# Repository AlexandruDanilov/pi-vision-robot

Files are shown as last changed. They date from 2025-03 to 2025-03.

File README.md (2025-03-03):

# Pi Vision Project Documentation

## Chapter I. Practical Utility

Pi Vision is a modular, smart webcam platform designed to keep the subject perfectly centered without reducing image quality. It processes images locally, so it does not affect your computer’s performance. This makes it ideal for streaming and videoconferencing.

The webcam works autonomously in any environment—as long as there is a subject to follow. It’s suitable for any workspace requiring a video connection and can be used for:

- **Videoconferences:** Keeps you centered without manual adjustments for a smooth, professional meeting.
- **Streaming:** Perfect for live streaming (games, events, etc.) by automatically focusing on the subject.
- **Video Recording:** Records high-quality videos like vlogs or tutorials, always keeping the subject in frame.
- **Mobile Robotics:** Can be integrated into mobile robots for autonomous navigation and enhanced interaction.

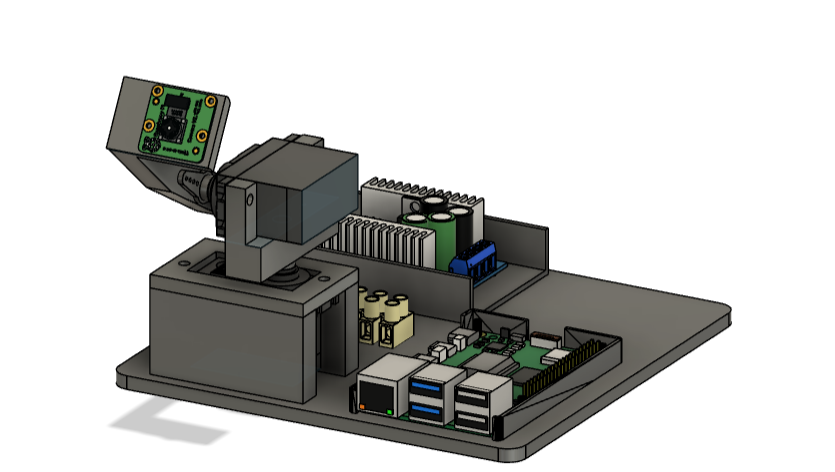
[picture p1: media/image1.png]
Prototype image 1


---

## Chapter II. Mechanics

### 1. Mechanical Design

- **Degrees of Freedom:**  
  The device uses two servo motors to allow two independent axes, giving a wide field of view. The design uses direct drive—meaning no extra gears or belts are required.

- **Modular Construction:**  
  The design is simple and modular, allowing easy attachment of different accessories (like sensor or mobile robot kits).

### 2. Construction Efficiency

- **3D Printing:**  
  Designed with Autodesk Fusion and sliced with Bambu Studio, the parts are optimized for 3D printing without supports and minimal material waste.  
  Printing time is kept under 8 hours, and the design is easily modifiable for different hardware.

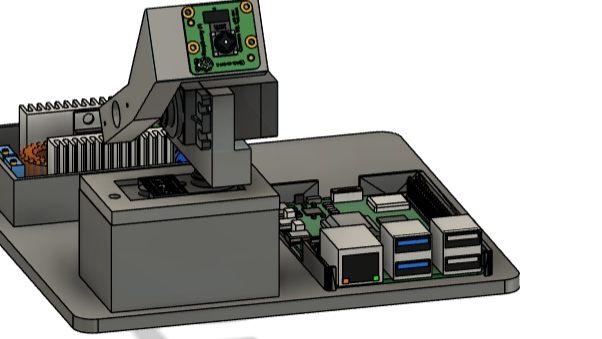
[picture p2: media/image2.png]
CAD image
  
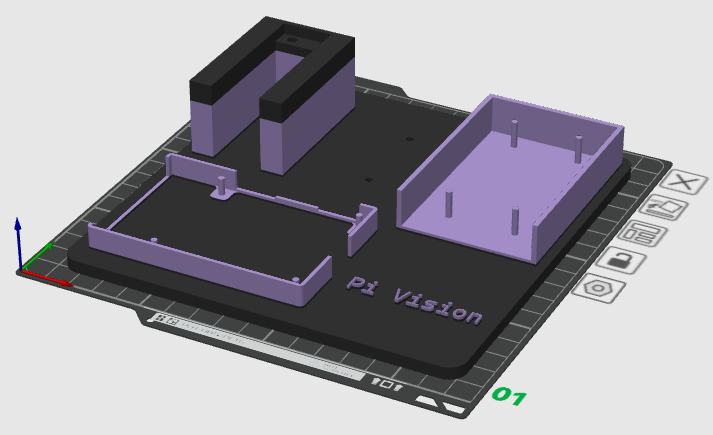
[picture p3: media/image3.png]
3D printable image


---

## Chapter III. Electronics

### 1. Microprocessor

**Raspberry Pi 5 (8GB):**  
  Handles image processing and sends directional commands. It also manages sensor data when additional modules are connected.  
  It’s compact, energy efficient, and supports a high-quality camera.

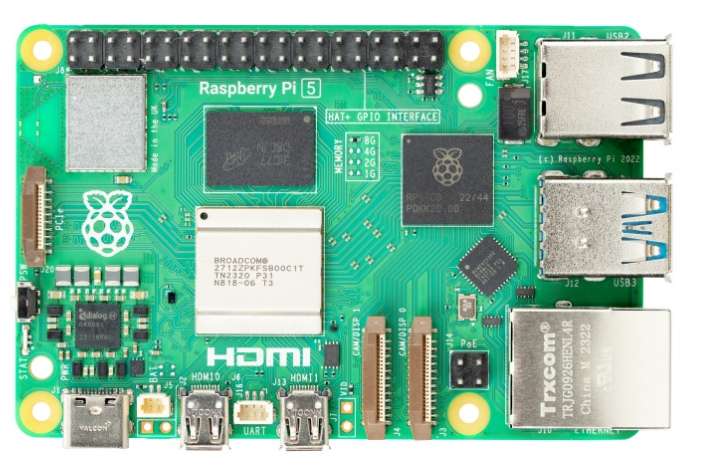
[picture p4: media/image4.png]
Raspberry Pi 5/8GB


### 2. Microcontroller

**Raspberry Pico:**  
  Offloads tasks from the Raspberry Pi and controls the servo motors using hardware PWM (which the Pi’s GPIO cannot do directly). The Pico is connected via UART for precise control.

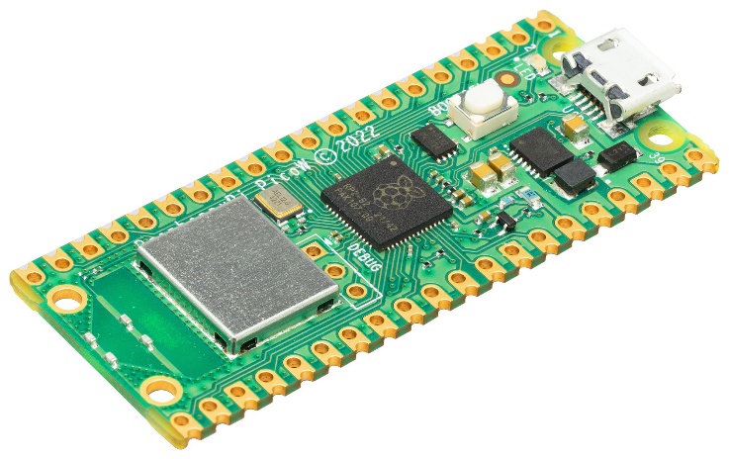
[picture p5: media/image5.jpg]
Raspberry Pico


### 3. Circuit Design

**Modular PCB:**  
  The microcontroller is mounted on a PCB with screw connectors, making it easy to expand and maintain without soldering.

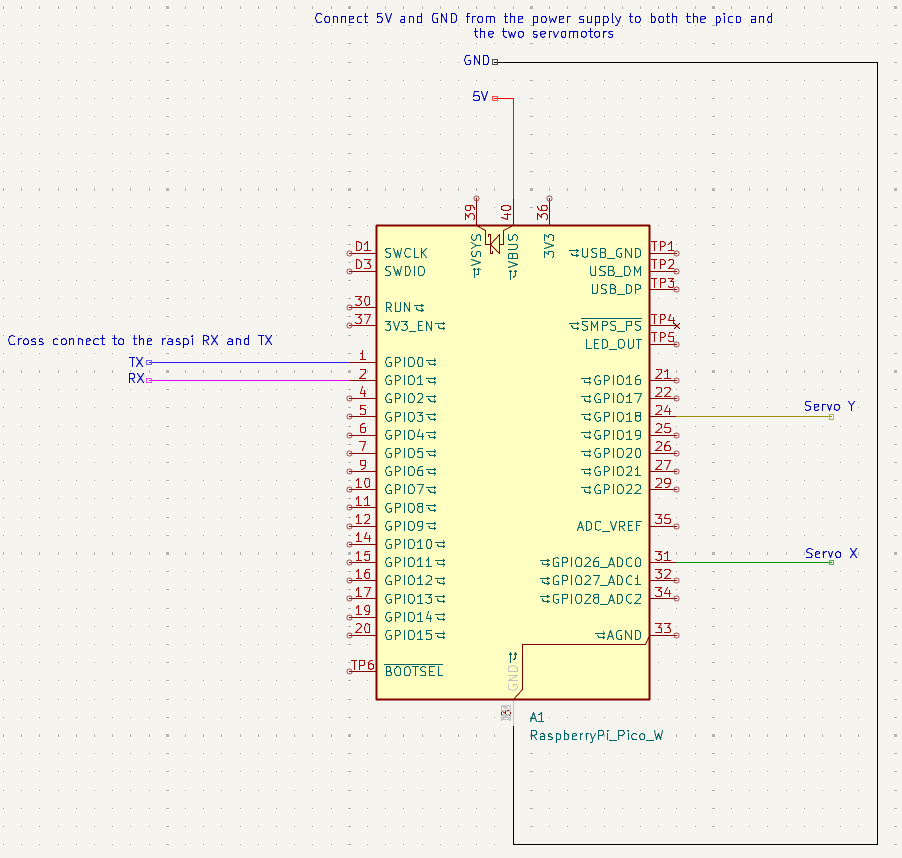
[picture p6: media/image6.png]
Circuit board example
  

### 4. Power Supply

**Two-Part System:**  
  - **Rectifier:** Converts AC to 20V DC for the primary power.
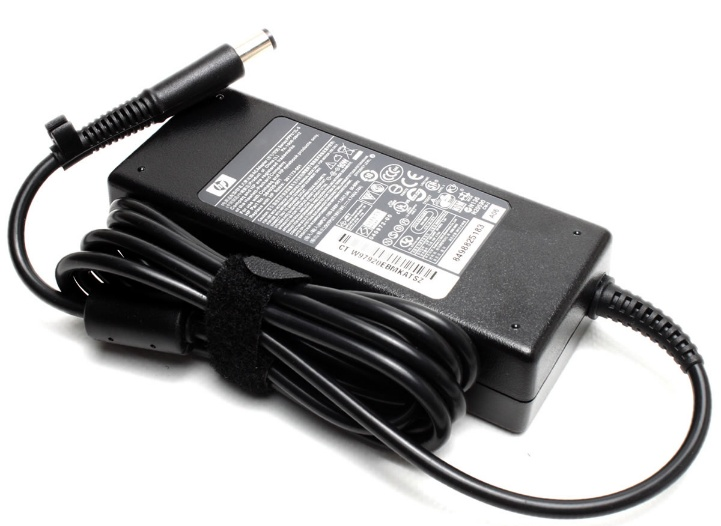
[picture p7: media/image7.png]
DC Power Supply

  - **Voltage Regulator:** Steps down 20V to 5V for both the servo motors and electronics, with built-in safety features against short circuits.  
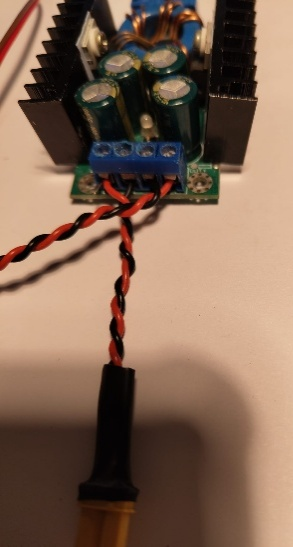
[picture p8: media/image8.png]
Voltage Regulator


### 5. Accessibility

**Easy Maintenance:**  
  Components are openly mounted and accessible, allowing quick troubleshooting with standard tools like a multimeter.

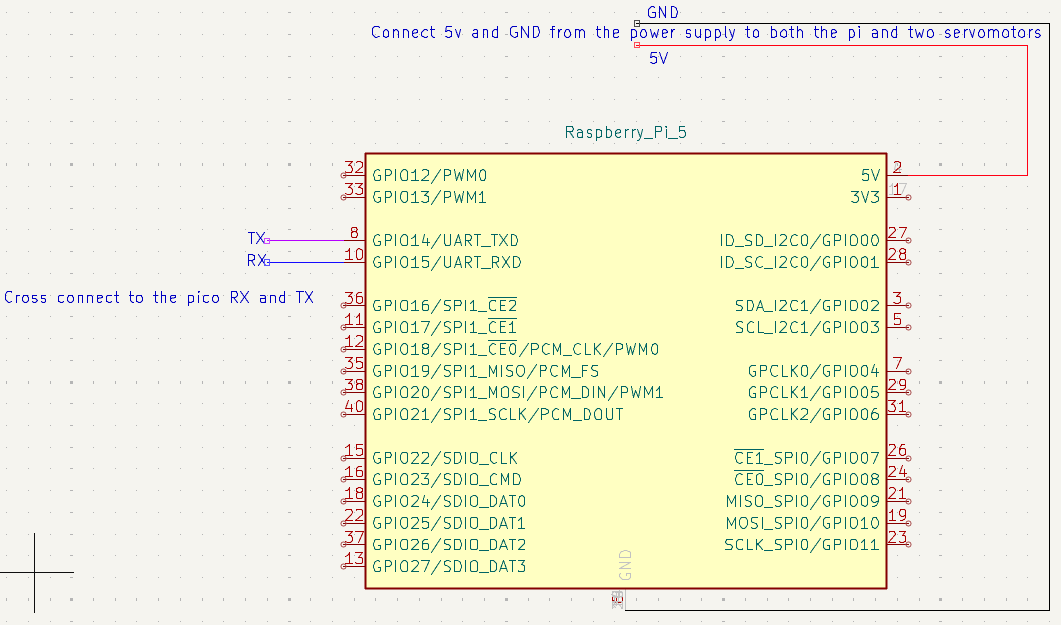
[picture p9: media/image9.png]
Circuit board drawing
  

### 6. Energy Efficiency

**Battery Operation:**  
  When powered by a 2s 75C 700mAh LIPO battery, the system can run for nearly 2 hours.

---

## Chapter IV. Software

### Dual Device Setup

**Raspberry Pi:**  
  Captures and processes images using OpenCV (cv2 with picamera2) and a pre-trained AI model (using TensorFlow Lite with MediaPipe Face Landmark Detection). It sends simple commands (up/down, left/right) via UART based on the subject’s position.

**Raspberry Pico:**  
  Receives the UART signals and controls the servo motors by converting PWM signals to specific angles. This helps in keeping the cables tension-free and the movements smooth.

### Operating Modes

**Tracking Modes:**  
  Various AI modules (face detection, object recognition, gesture detection, etc.) can be run on the Raspberry Pi.
**Monitoring Modes:**  
  The system can work without active tracking—using keyboard controls, a mobile app, or auto-scanning—plus display sensor data if a sensor kit is attached.

---

## Chapter V. Industrial Design

### 1. Design and Assembly

**3D Printed Parts:**  
  The design in Autodesk Fusion is optimized for 3D printing without supports, ensuring minimal material waste and strong parts.  
  It is designed for fast printing (under 8 hours) and can be printed on compact machines like the Prusa Mini or Bambulab A1 Mini.

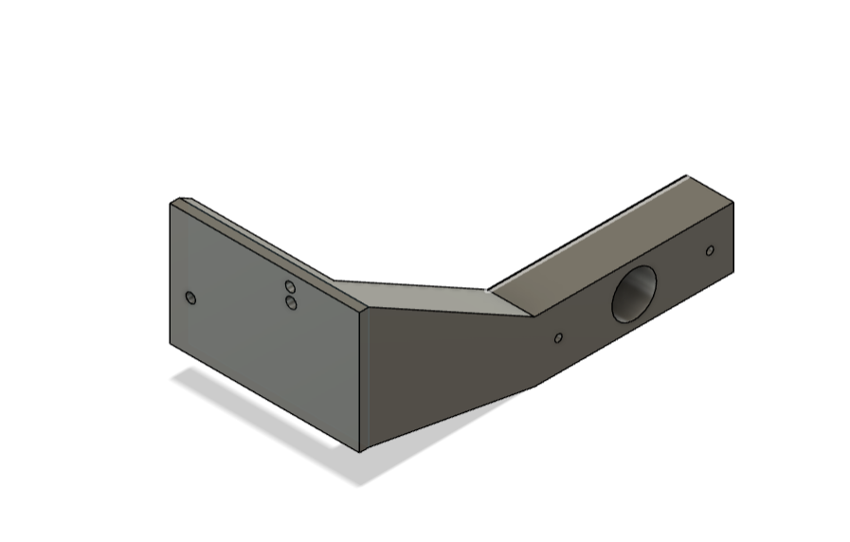
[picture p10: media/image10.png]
Part 2
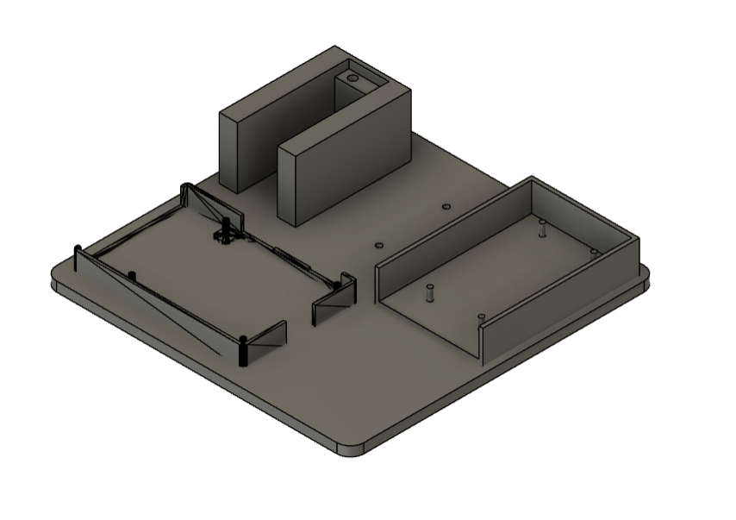
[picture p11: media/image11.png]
Part 1
   
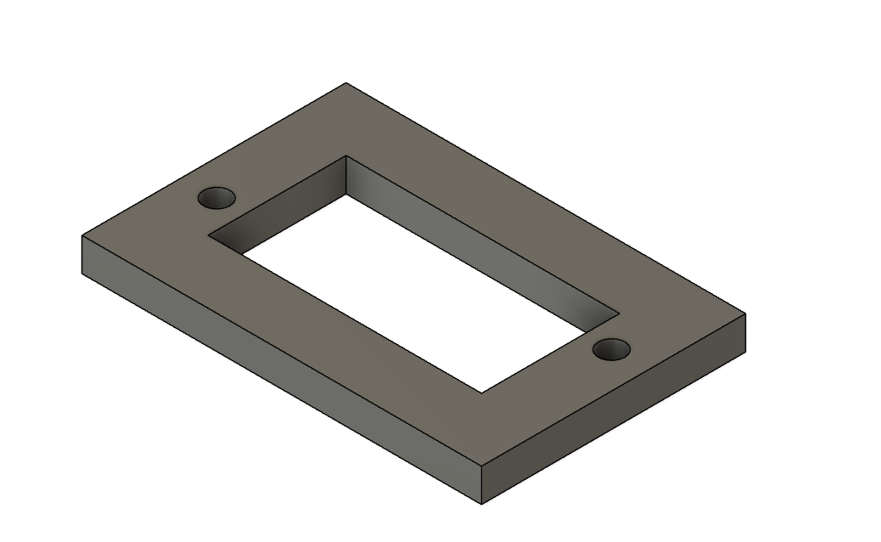
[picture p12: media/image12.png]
Part 3
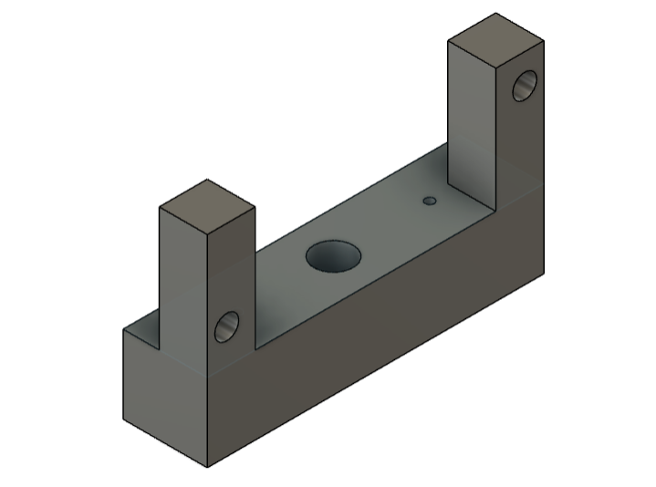
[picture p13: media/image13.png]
Part 4.1
   
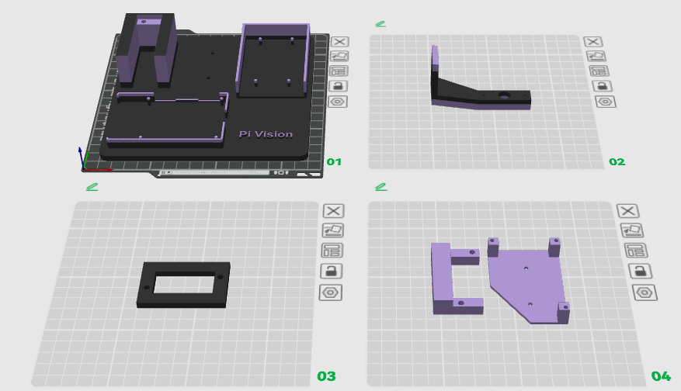
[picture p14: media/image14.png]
Assembly overview


### 2. Quick Assembly

**Assembly Time:**  
  - 3D printing: ~ 7-8 hours  
  - Mechanical assembly: ~30 minutes  
  - Electronics assembly: 15–60 minutes (depending on PCB pre-assembly)  
  - Programming: ~10 minutes

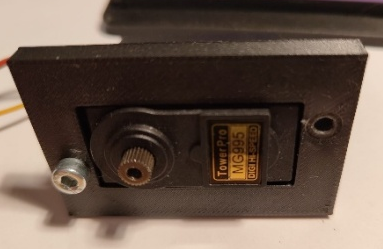
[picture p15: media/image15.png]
Component assembly
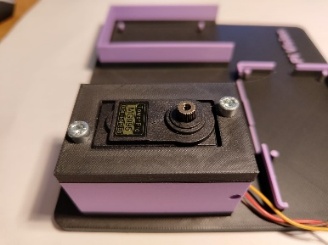
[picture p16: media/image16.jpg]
Device close-up
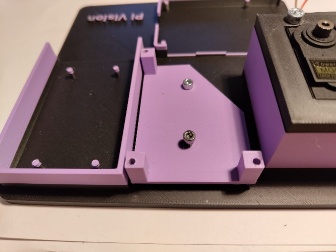
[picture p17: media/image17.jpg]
Electronics assembly
      
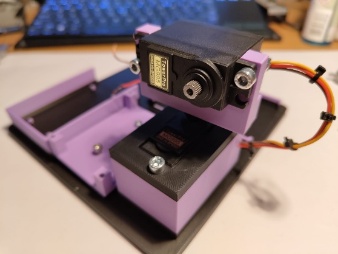
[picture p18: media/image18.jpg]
Small device image
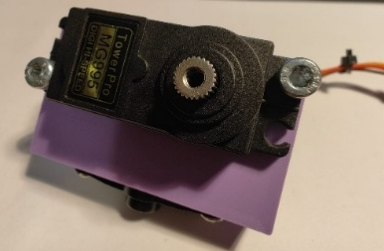
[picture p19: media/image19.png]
Additional device image
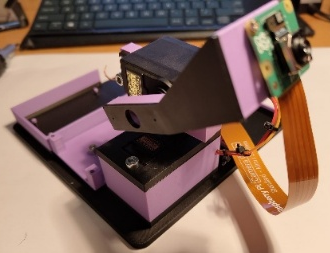
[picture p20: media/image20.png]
      
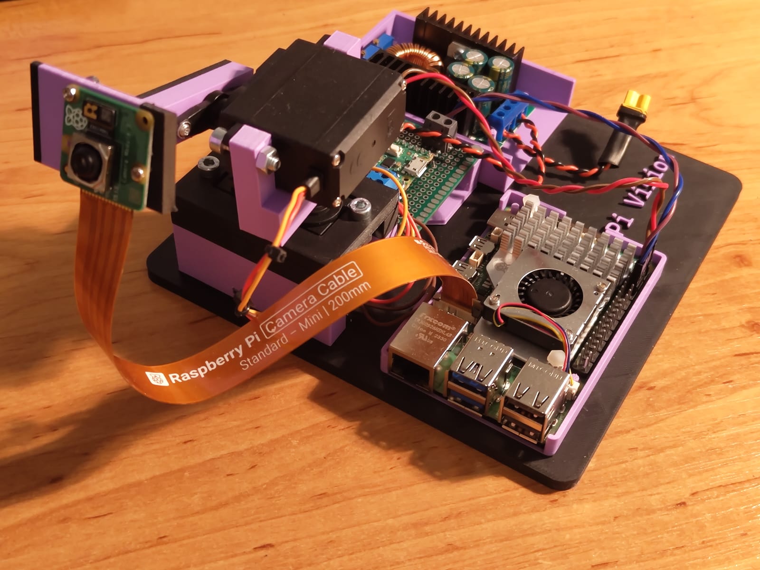
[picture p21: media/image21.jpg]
  

### 3. Build Efficiency

**Material Use:**  
    Uses about 200 grams of filament. The modular design fits well with other products in its class. It can be easily adapted for various technical skills and budgets (for example, using a Raspberry Pi 4 might eliminate the need for a Pico).

### 4. Future Developments / Coming Soon

- Android app for remote control and monitoring.
- Server mode for external network access.
- Adding a degree of freedom for depth control (zooming).
- A graphical interface for operating modes.
- Implementation as an external USB webcam.

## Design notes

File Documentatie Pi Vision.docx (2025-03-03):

Pi Vision

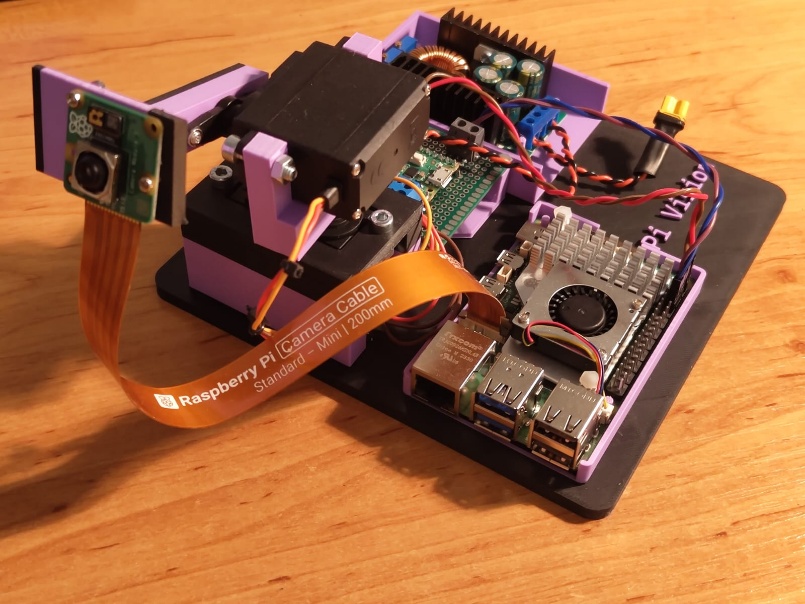
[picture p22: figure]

În secolul XXI, robotul va prelua locul pe care îl ocupau sclavii în cadrul civilizaţiilor antice. (Nikola Tesla)

Capitolul I. Utilitate practică

Pi Vision este o platformă modulară tip webcam inteligent. Are scopul de a încadra corect subiectul într-un cadru fără a reduce calitatea imaginii. Poate fi folosit drept periferic, procesarea de imagine este realizată activ de dispozitiv, așadar performanțele computerului la care este conectat nu sunt afectate. Este ideal pentru streaming sau videoconferințe.

Webcam-ul este complet autonom și funcționează indiferent de mediu. Singurul criteriu de funcționare este prezența unui subiect care trebuie ținut în centrul cadrului.

Este util în orice spațiu de lucru care necesită conexiune video. Poate fi folosit atât pentru monitorizarea unor subiecte cât și pentru conferințe video sau streaming. Modulul este compact și poate fi accesat prin WiFi, acesta poate fi alimentat atât la priză cât și de la o baterie.

Spre deosebire de alte dispozitive tip gimbal care au funcții inteligente de urmărire a subiectului, toată procesarea de imagine se face local, așa că nu consumă resurse suplimentare asigurând o funcționare rapidă și eficientă.

Prezintă o multitudine de moduri de rulare, fiind aplicabil în orice domeniu, atât pe plan industrial cât și pe plan personal. Este proiectat eficient și ușor de printat 3D, poate fi construit de oricine indiferent de competențele tehnice, ghidul de asamblare fiind detaliat. Fabricarea în masă este posibilă fără prea multe modificări. Costul de producție este mediu, aproximativ 1200 de lei. Prețul mediu al dispozitivelor tip gimbal AI este de 900 de lei, dar necesită un smartphone pentru a funcționa. Cu toate că amprenta pe birou este ceva mai mare decât a unui gimbal comercial, construcția compactă și înălțimea redusă asigură o bună integrare în majoritatea setupurilor de gaming sau home office.


Scenariile posibile de utilizare pentru Pi Vision includ:

1. Videoconferințe: Pi Vision poate fi utilizat pentru a asigura că utilizatorul este întotdeauna centrul atenției în cadrul unei videoconferințe, fără a fi nevoie de ajustări manuale ale camerei. Acest lucru asigură o experiență fluidă și profesională în timpul întâlnirilor online.
2. Streaming: Platforma poate fi folosită pentru streaming în timp real, fie că este vorba de streaming de jocuri video, de evenimente live sau de alte activități online. Funcționalitatea sa de urmărire a subiectului asigură că acesta rămâne în centrul atenției în timpul fluxului video.
3. Înregistrare de videoclipuri: Pi Vision poate fi utilizat pentru a înregistra videoclipuri de calitate, fie că este vorba de vloguri, tutoriale sau alte conținuturi video. Capacitatea sa de a urmări subiectul asigură că acesta este mereu în cadru, fără a necesita intervenția manuală a utilizatorului.
4. Monitorizarea unui animal de companie: Pi Vision poate fi folosit pentru a monitoriza activitățile și comportamentul unui animal de companie în timp real. Acest lucru este util pentru proprietarii de animale care doresc să supravegheze animalul în timp ce sunt plecați de acasă.
5. Monitorizarea mediului ambiental: Cu ajutorul accesoriilor potrivite, cum ar fi senzori de temperatură, umiditate sau calitatea aerului, Pi Vision poate fi utilizat pentru a monitoriza mediul ambiental în diverse spații, cum ar fi locuințe, birouri sau spații industriale. Această funcționalitate este utilă pentru a asigura un mediu sănătos și confortabil.
6. Integrarea pe un robot mobil: Pi Vision poate fi integrat pe un robot mobil pentru a oferi capacități suplimentare de navigare autonomă, monitorizare a mediului înconjurător și interacțiune cu utilizatorii. Acest lucru extinde gama de aplicații și funcționalități ale Pi Vision în domenii precum cercetarea, explorarea și asistența personală.

Capitolul II. Mecanică

1. Complexitate mecanică

Dispozitivul are două grade de libertate date de cele două servomotoare și asigură o rază mare de acțiune și un cadru larg pentru imagine. Cele două grade de libertate sunt acționate independent, mecanismele de mișcare fiind de tip direct drive. Astfel nu sunt necesare reductoare, curele sau alte modalități de transmisie, butariele fiind montate direct pe axul care iese din fiecare motor. Montarea este una simplă, fiind folosite servo hornurile incluse în pachet, iar datorită masei reduse nu sunt necesare șuruburi pentru asigurarea acestora. De asemenea, platforma este una modulară și acceptă mai multe tipuri de accesorii (kit senzori, kit robot mobil, etc.).

2. Eficiență in construcție

Robotul a fost realizat cu ajutorul printării 3D, motiv pentru care am avut nevoie de un software de tip CAD și de un slicer. Dispozitivul este proiectat în Autodesk Fusion. Are un design modular și ușor de modificat pentru a obține compatibilitate cu alte piese. Poate fi ușor modificat pentru folosirea unor servomotoare mai mici, coborator de tensiune sau placă Raspberry Pi de modele diferite. De asemenea, este proiectat pentru a fi printat fără suport, fiind eficient în consumul de material. În slicer (Bambu Studio), am stabilit orientarea corectă a pieselor pentru a asigura un timp de construcție redus (sub 8 ore de print), dar calitate sporită. Construcția este eficientă prin optimizarea topologică și mijloacele de printare cu risipă minimă de filament.

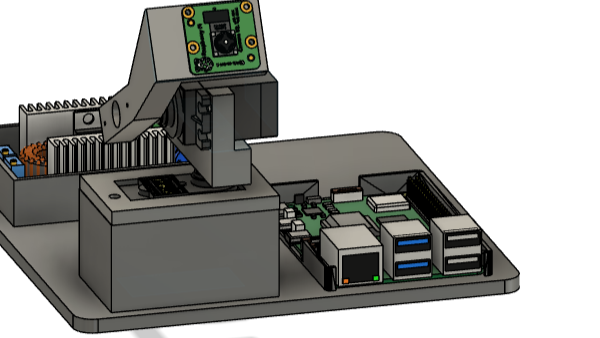
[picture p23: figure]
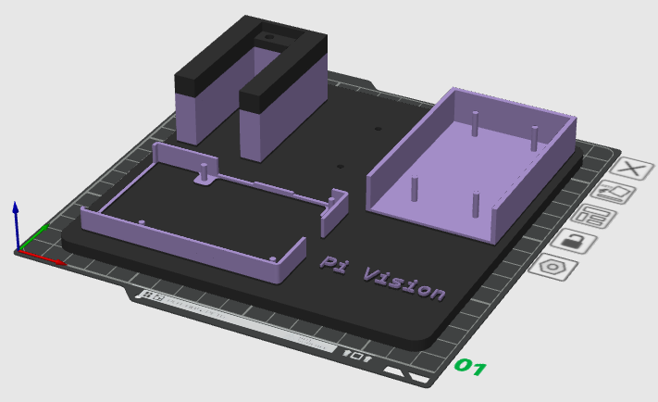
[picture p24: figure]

Capitolul III. Electronică

1. Microprocesor

Pentru procesarea de imagine, am ales să folosim un Raspberry Pi model 5 cu 8GB de memorie, datorită posibilității de a adăuga un cooler activ și a camerei de calitate care face parte din ecosistemul său. De asemenea, este o placă compactă, iar consumul de curent este nesemnificativ. Pe lângă procesarea de imagine, Raspberry Pi se ocupă și de transmiterea parametrilor de direcție către microcontroller sau de citirea/interpretarea datelor de la senzori atunci când sunt conectate module de expansiune.

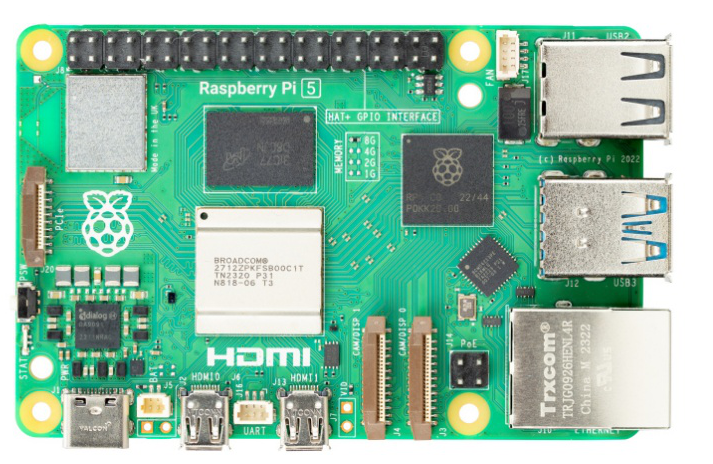
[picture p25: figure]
Raspberry Pi 5/8GB

2. Microcontroller

Am optat pentru folosirea unui microcontroller, în acest caz Raspberry Pico, din mai multe motive:

  a. Evitarea suprasolicitării microprocesorului: Folosirea unui microcontroller separat ajută la distribuirea sarcinilor și la evitarea suprasolicitării microprocesorului principal, în acest caz Raspberry Pi. Alocarea unui fir de execuție pentru fiecare grad de libertate pe microcontroller asigură o gestionare eficientă a sarcinilor.
  b. Controlul motoarelor: Raspberry Pi nu permite controlul direct al motoarelor utilizând pinii GPIO pentru că aceștia suportă doar PWM software, în timp ce servomotoarele nu dispun de această funcție. Prin folosirea unui microcontroller separat, conectat la unitatea principală de calcul prin UART, se rezolvă această problemă, asigurându-se un control precis al motoarelor.

Folosirea unui microcontroller separat, precum Raspberry Pico, conectat la Raspberry Pi prin UART, permite o soluție eficientă din punct de vedere al spațiului, timpului și puterii de procesare, adresând în mod eficient cerințele sistemului.

RASPBERRY-PI RASPBERRY PI PICO W SBC, Raspberry Pi Pico W, RP2040, ARM Cortex-M0+, 264kB RAM, 2MB Flash, Wifi, Micro-USB

3. Circuite

Microcontrollerul este montat pe o placă PCB construită pe un protoboard, iar toate conexiunile sunt realizate prin intermediul conectorilor cu surub. Această abordare oferă posibilități extinse de expansiune a platformei și elimină necesitatea lipirii efective a firelor. Astfel, sistemul devine modular și permite adăugarea sau schimbarea componentelor fără a fi nevoie de modificări semnificative ale configurației fizice. Utilizarea conectorilor cu surub facilitează și procesul de depanare și întreținere a sistemului, oferind o soluție practică și flexibilă pentru integrarea și dezvoltarea platformei.

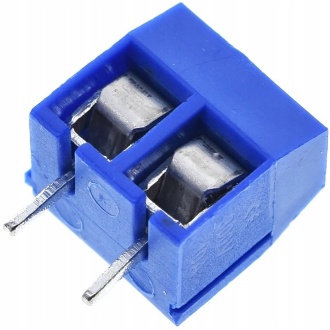
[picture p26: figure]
Conector terminal cu surub, 2 pini - eMAG.ro

4. Senzori

Când sistemul este utilizat pentru monitorizarea mediului ambiental, se pot folosi senzori de tip Vernier conectați la un microcontroller separat, cum ar fi Arduino Uno. Datele colectate de acești senzori pot fi transmise prin interfața serială către Raspberry Pi, unde vor fi prelucrate și interpretate ulterior. Această abordare permite utilizarea unei game variate de senzori specializați pentru monitorizarea parametrilor specifici mediului ambiental, cum ar fi: umiditatea, concentrația de gaze etc.

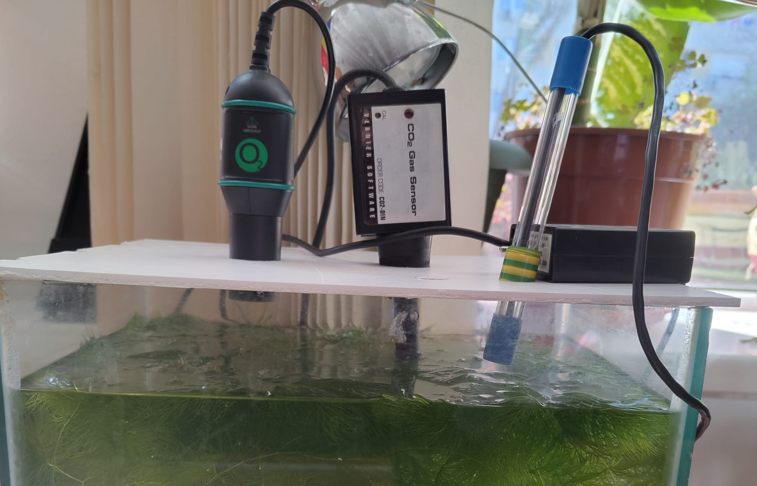
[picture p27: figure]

Într-o altă configurație, pentru monitorizarea mediului ambiental, se pot monta direct diversi senzori pe Raspberry Pi pentru aplicații generale. De exemplu, într-un setup de acasă, se poate utiliza un senzor PIR (infraroșu pasiv) pentru a detecta mișcarea și a porni sistemul când este activat. În plus, un senzor ultrasonic poate fi folosit pentru a detecta prezența unei persoane la birou, declanșând programul de urmărire facială. Această abordare elimină necesitatea utilizării unui microcontroller separat și simplifică configurația sistemului, permițând monitorizarea mediului ambiental și activarea funcțiilor corespunzătoare direct de către Raspberry Pi.

5. Alimentare

Partea de alimentare a sistemului este alcătuită din două elemente distincte:

Sursa de alimentare redresoare: Această componentă transformă curentul alternativ în 20V curent continuu. Este responsabilă pentru furnizarea unei surse de alimentare primare pentru întregul sistem.

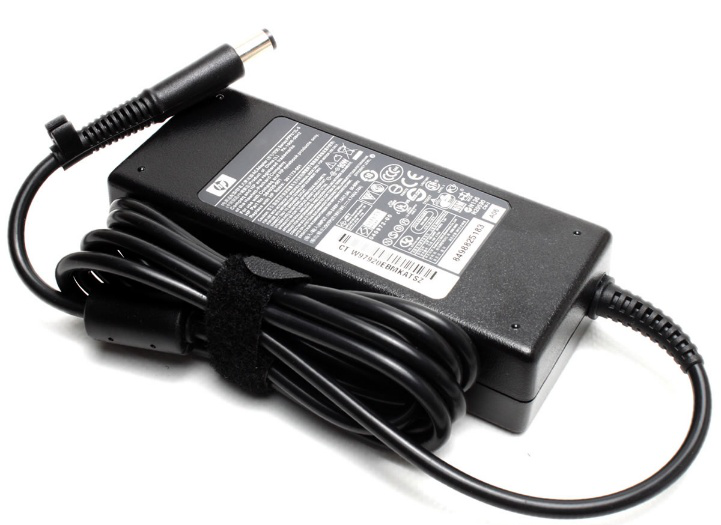
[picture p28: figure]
Sursa DC

Coborâtorul de tensiune: Coboră tensiunea de la 20V la 5V, care este tensiunea corespunzătoare atât pentru servomotoare, cât și pentru electronica logică a sistemului. Acest coborâtor de tensiune asigură o alimentare stabilă și potrivită pentru toate componentele din sistem.

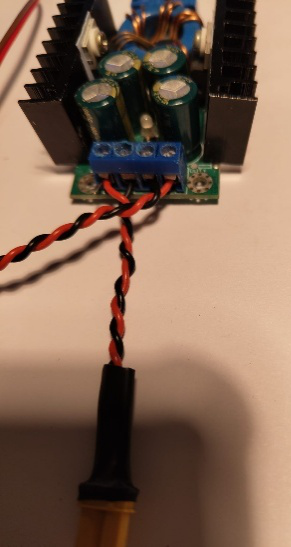
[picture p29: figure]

Ambele elemente sunt dotate cu protecție anti-scurt și siguranță pasivă, ceea ce înseamnă că există măsuri de protecție împotriva scurtcircuitelor și a altor probleme de alimentare. Astfel, riscul de distrugere accidentală a componentelor este redus în cazul unei conectări greșite a firelor. Această configurație oferă o soluție sigură și fiabilă pentru partea de alimentare a sistemului.

6. Accesibilitate

Toate componentele sunt montate la vedere și ușor accesibile, iar electronica este concepută în așa fel încât, indiferent de problemă, piesele să fie ușor interschimbabile. Conexiunile sunt sigure, dar au părți expuse, permițând efectuarea de depanări folosind un multimetru fără a fi nevoie să desfacem robotul.

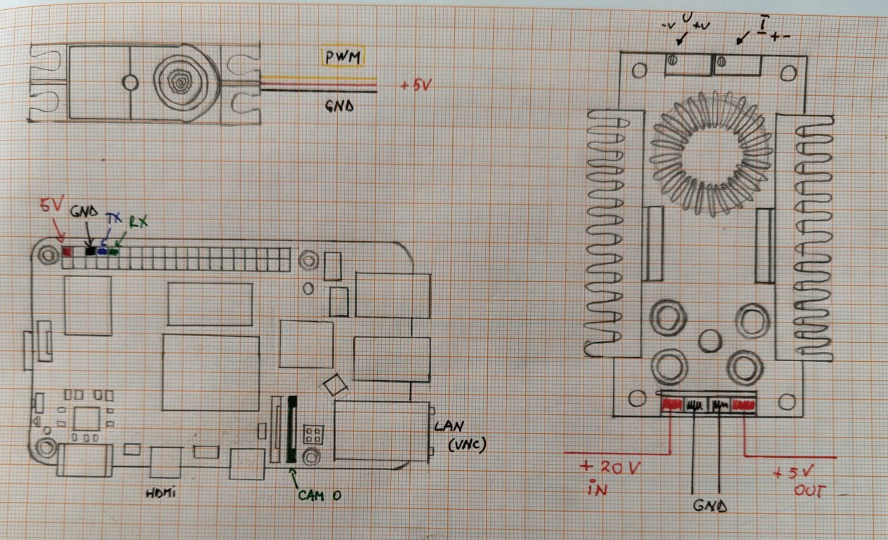
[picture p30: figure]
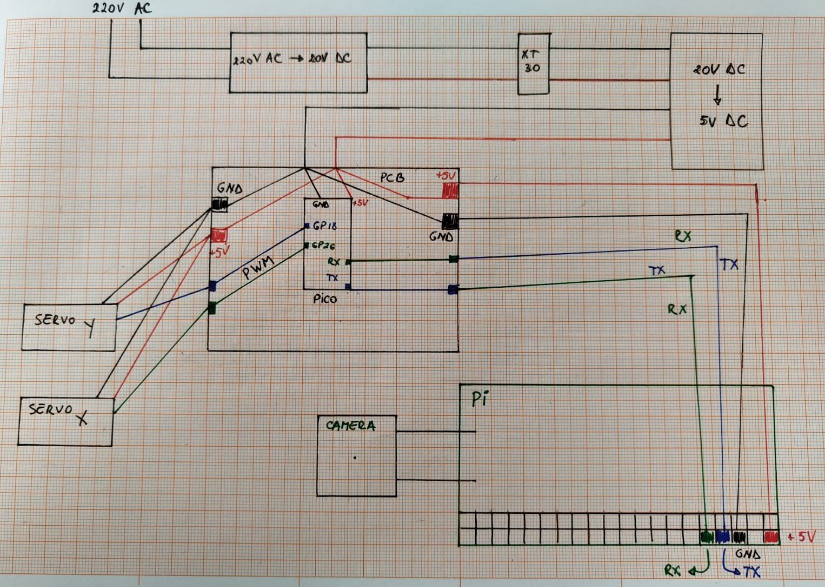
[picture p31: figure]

Această abordare oferă un avantaj considerabil în ceea ce privește întreținerea și repararea sistemului, deoarece permite diagnosticarea rapidă și rezolvarea problemelor fără a fi necesar să se demonteze întregul dispozitiv. Astfel, se optimizează timpul și efortul necesar pentru întreținerea și repararea sistemului, facilitând o intervenție rapidă și eficientă în caz de necesitate.

7. Eficiență în construcție

Sistemul este eficient din punct de vedere energetic, fiind compact si folosind componente de mici dinemsinui cu consum redus. Atunci cand este alimentat de la baterie are o autonomie de aproape 2 ore folosind o celula LIPO 2s 75C de 700mAh.

Capitolul IV. Software

Există două dispozitive programabile: Raspberry Pi 5 și Raspberry Pico. Raspberry Pi este responsabil de procesarea imaginii și returnarea direcțiilor, în timp ce Raspberry Pico este responsabil de locomotie prin controlul celor două servomotoare. Din Raspberry Pi sunt trimise patru instrucțiuni de bază pentru controlul coordonatelor (sus/jos, stânga/dreapta). Atunci când subiectul este așezat corespunzător în cadru, nu este trimisă nicio instrucțiune. În Raspberry Pico, aceste instrucțiuni sunt interpretate pentru ajustarea unghiului-țintă cu un grad fix pe fiecare axă (Ox respectiv Oy).

Raspberry Pi: Captarea imaginii și filtrarea (rezoluție, format, aspect, culoare) se efectuează cu ajutorul cv2 prin picamera2. Procesarea efectivă a imaginii se realizează cu ajutorul unui model de inteligență artificială preantrenat care folosește TensorFlow Lite (MediaPipe Face Landmark Detection).

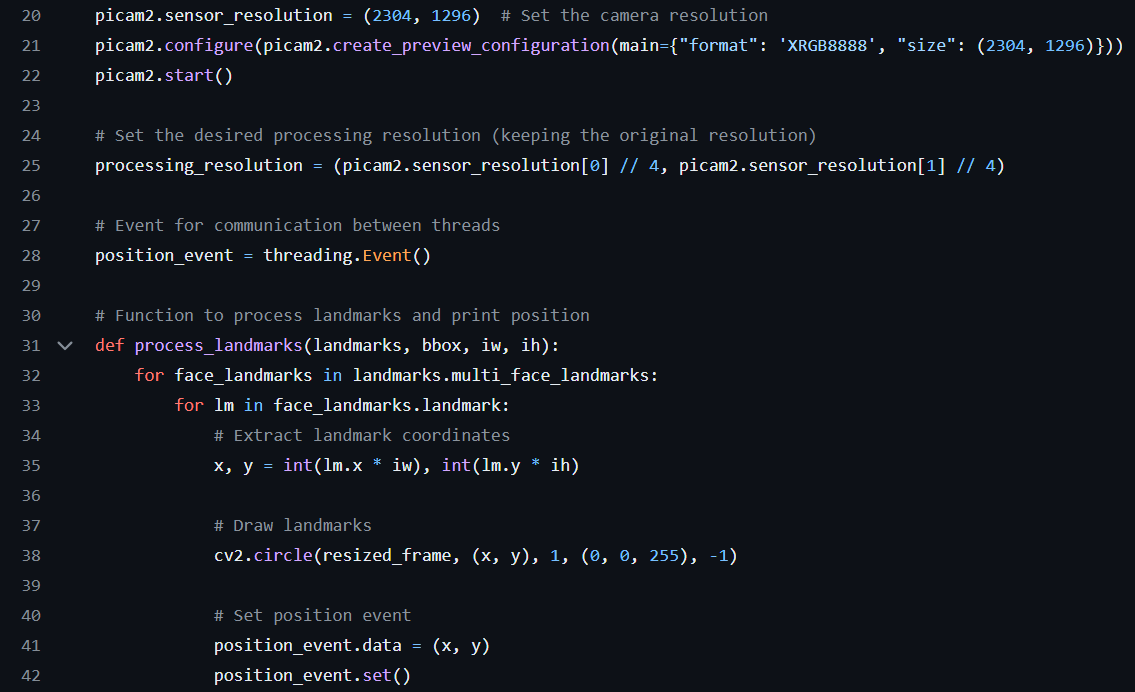
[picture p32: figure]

Programul trimite prin UART direcțiile către microcontrollerul de locomotie, raportat la poziția subiectului în cadru.

Semnalele sunt returnate sub formă de șir de caractere pentru a facilita procesele de depanare (debugging). Axele sunt separate în două structuri distincte și scrise pe rânduri diferite pentru a decelera trimiterea comenzilor către Raspberry Pico (izolând fenomenul de jitter al servomotoarelor).

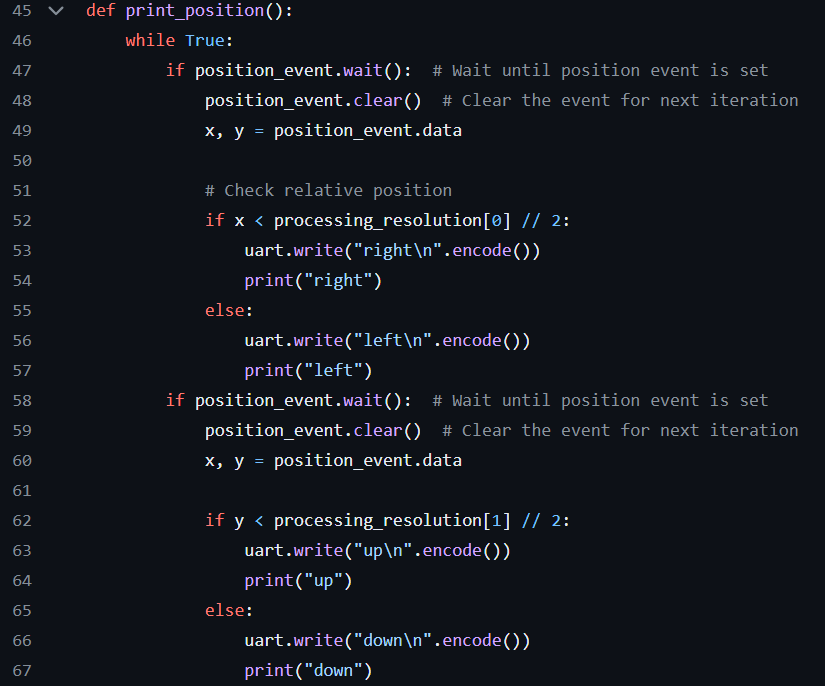
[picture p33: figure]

Raspberry Pico: Controlul efectiv al servomotoarelor se efectuează prin controlul efectiv al ciclurilor de lucru PWM. Este implementat un convertor din semnal PWM către unghi pentru a putea limita cu ușurință raza de acțiune a motoarelor. Razele de acțiune sunt stabilite astfel încât cablurile să nu se afle sub tensiune la capete, piesele având clearance, fiind astfel o abordare foolproof spre implementarea locomotiei.

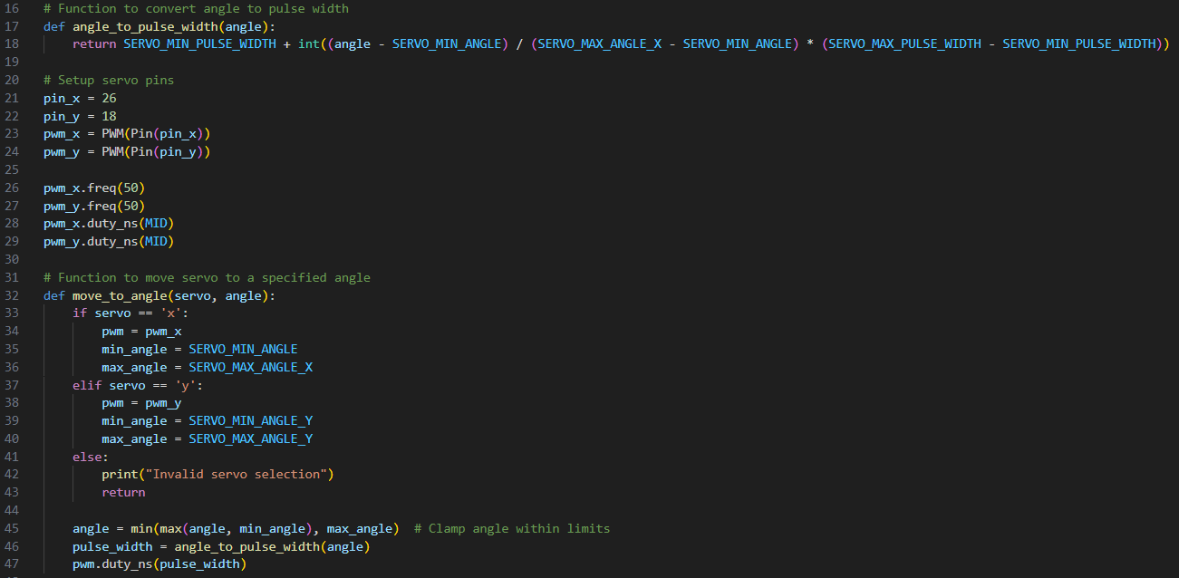
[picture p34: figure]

Semnalul UART este apoi decodat, folosit pentru a schimba coordonatele (prin cele 2 unghiuri-țintă)

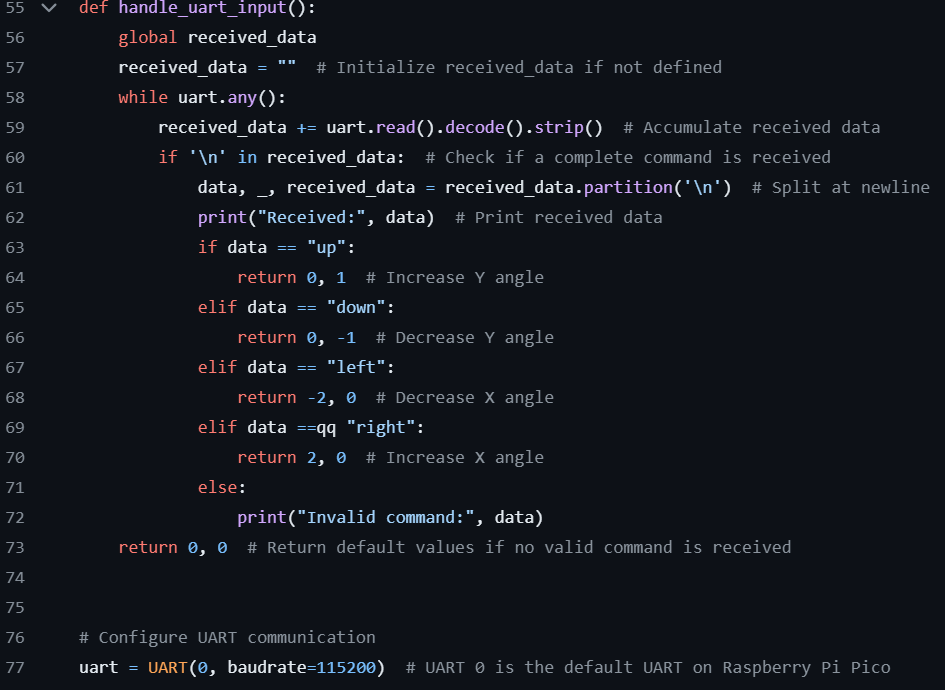
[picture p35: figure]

Moduri de rulare:

Programul pentru Raspberry Pico este unul fix și invariabil, în timp ce pe Raspberry Pi există mai multe programe care pot rula în funcție de scenariul de utilizare. Detectarea poate fi facială, recunoașterea umană, identificarea obiectelor, gesturile etc. Toate aceste module de inteligență artificială pot fi implementate cu ușurință folosind MediaPipe. Există și moduri de rulare care nu implică identificare sau urmărire, ci doar monitorizare. În acest caz, controlul motoarelor se face prin tastatură sau aplicație pe telefon sau prin scanare automată a imaginii. De asemenea, în modurile de monitorizare, datele de la senzori pot fi afișate spre interpretare (necesită kit senzori). Această flexibilitate oferă utilizatorului posibilitatea de a adapta funcționalitatea sistemului în funcție de nevoile și preferințele sale specifice.

Capitolul V. Design industrial

1. Poriectare si constructie efectiva

Proiectarea a fost realizata in Autodesk Fusion. Modelul a fost realizat in asa fel incat sa poata fi printat pe bucati fara structuri de suport si cu risipa minima de filament. Optimizarea topologica se regaseste si in ghidul de asamblare unde este indicata detaliat asezarea corecta a pieselor pe suprafata de printare in vederea unei rezistente mecanice sporite. Printarea 3D dureaza sub 5 ore, iar volumul de printare necesar este redus (Poate fi printat inclusiv pe imprimante de molum mic cum ar fi Prusa Mini sau Bambulab a1 Mini).

Piesa 2
piesele 1 -> 4 (piesa 4.1 stanga, 4.2 dreapta)

2. Timp de constructie

Timpul de constructie este relativ redus (printarea dureaza aproximativ 5 ore, asamblarea mecanica 30 de minute, asamblarea electronicii 15 minute in cazul in care placuta pcb este preasamblata, o ora fara placuta pcb, incarcarea programelor 10 minute)

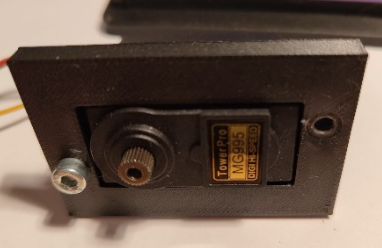
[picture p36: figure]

3. Eficienta in constructie

Consumul de filament este redus (in jur de 200 de grame). De asemenea amprenta modulului este similara cu cea a produselor din aceeasi clasa. Piesele sunt usor de achizitionat fiind larg disponibile. Designul modular permite o varietate mare de piese care pot fi folosite, proiectul poate fi adaptat pentru orice nivel de cunostinte si buget (raspberry pi 4 permite folosirea hardware pwm, nu ar mai fi necesar un raspberry pico, asadar complexitatea scade)

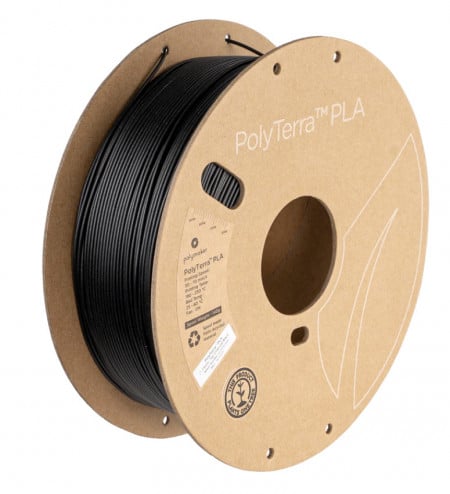
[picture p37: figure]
Polymaker PolyTerra PLA Charcoal Black - Filamente3D.ro
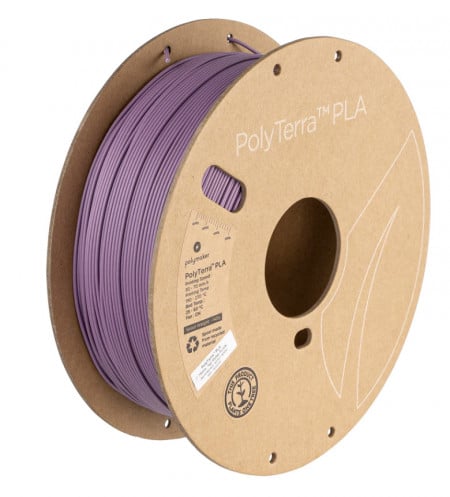
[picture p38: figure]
Polymaker PolyTerra PLA Muted Purple - Filamente3D.ro

4. Resurse web

Toate componentele si resursele intelectuale sunt disponibile pe pagina de github a proiectului, poate fi usor accesat si modificat de oricine. Softwareul folosit atat pentru proiectare mecanică cât și pentru software sunt disponibile pe pagina de github a proiectului.

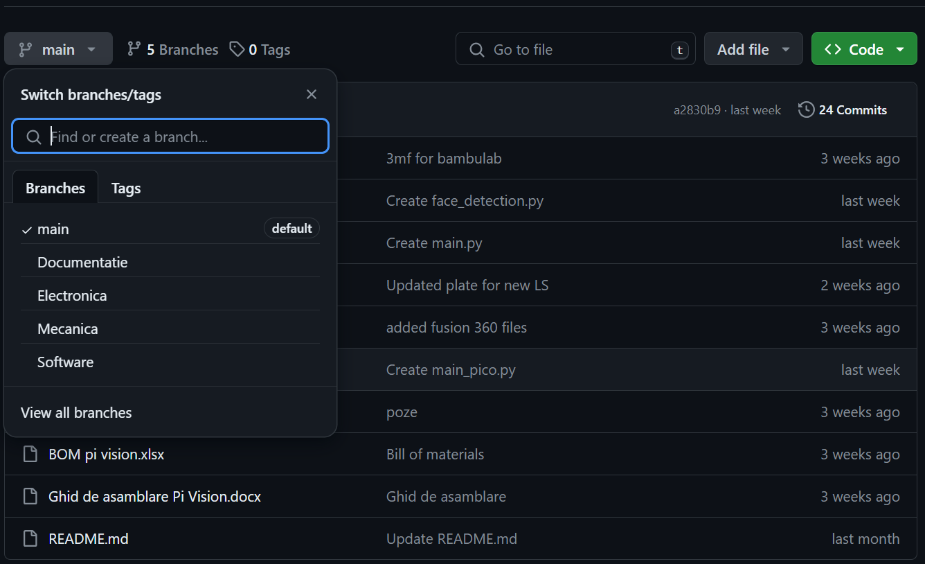
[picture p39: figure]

5. Planuri de dezvoltare

- Implememtarea unei aplicatii android pentru monitorizare/control remote

- Functionalitate in regim server pe retea externa

- Adaugarea unui grad de libertate suplimentar pentru adancime (se apropie/indeparteaza de subiect)

- Adaugarea modurilor de rulare cu dezvoltarea unei aplicatii grafice

- Implementarea proiectului ca webcam extern USB

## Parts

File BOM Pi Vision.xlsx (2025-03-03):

Nr crt | Nume Produs | Link | Nr Bucati | Pret unitar (Ron) | Pret total (Ron)
1 | Incarcator universal, putere 120W | https://www.emag.ro/incarcator-universal-pentru-laptop-putere-120w-10-mufe-conectoare-compatibil-cu-asus-acer-hp-lenovo-dell-compaq-samsung-sony-electroaz-ali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 | 1 | 50 | 50
2 | Mufa xt30 mama | https://sogest.ro/mufe-adaptoare-ac-dc/mufa-alimentare-dc-xt30-mama-2-pini-cu-lipire-pe-cablu-15a-500v-amass-xt30u-f | 1 | 5 | 5
3 | Mufa xt30 tata | https://sogest.ro/mufe-adaptoare-ac-dc/mufa-alimentare-dc-xt30-tata-2-pini-pe-cablu-lipite-15a-500v-amass-xt30u-m | 1 | 5 | 5
4 | Set tuburi termocontractabile | https://sogest.ro/tuburi-termocontractabile/set-tuburi-termocontractabile-10cm-negre-170buc | 1 | 42 | 42
5 | Set de fire siliconice Plusivo (22AWG, 6 culori, 7m fiecare) | https://www.optimusdigital.ro/ro/kituri/9514-set-de-fire-siliconice-22awg-6-culori-7m-fiecare.html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 | 1 | 45 | 45
6 | Modul sursa coborator de tensiune reglabil | https://www.sigmanortec.ro/Modul-sursa-coborator-tensiune-reglabil-300W-8A-p174825734?gad_source=1 | 1 | 36 | 36
7 | Protoboard | https://www.optimusdigital.ro/ro/prototipare-cablaje-de-test/723-placa-de-test-universala-verde-50x70-mm.html | 1 | 2 | 2
8 | Raspberry Pico W | https://www.optimusdigital.ro/ro/placi-raspberry-pi/12394-raspberry-pi-pico-w.html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 | 1 | 34 | 34
9 | Terminal | https://www.optimusdigital.ro/ro/conectori/197-conector-cu-surub-3p-2-buc-.html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 | 2 | 1.5 | 3
10 | Motor Servo MG995 11KG 180 Grade | https://ardushop.ro/ro/home/94-servomotor-mg995.html?search_query=servo&results=19 | 2 | 27 | 54
11 | Raspberry Pi 5/8GB | https://www.optimusdigital.ro/ro/placi-raspberry-pi/12929-raspberry-pi-5-8gb.html | 1 | 449 | 449
12 | Card de memorie micro SD | https://conectica.ro/dispozitive-mobile/carduri-de-memorie/card-de-memorie-micro-sdhc-32gb-clasa-10-adaptor-sd-adata-ausdh32guicl10-ra1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 | 1 | 20 | 20
13 | Ventilator pentru Raspberry pi 5 | https://www.optimusdigital.ro/ro/accesorii/12940-ventilator-pentru-raspberry-pi-5.html | 1 | 28 | 28
14 | Modul Camera 3 pentru Raspberry Pi | https://www.optimusdigital.ro/ro/camere/12607-modul-camera-3-pentru-raspberry-pi.html | 1 | 138 | 138
15 | Cablu pentru Camera Raspberry Pi 5 Standard-Mini 200mm | https://www.optimusdigital.ro/ro/accesorii/12944-cablu-pentru-camera-raspberry-pi-5-standard-mini-200mm.html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 | 1 | 6 | 6
16 | Set 1280 suruburi hexagonale, zggzerg, cu saibe plate si de blocare | https://www.emag.ro/set-1280-suruburi-hexagonale-zggzerg-cu-saibe-plate-si-de-blocare-cutie-de-depozitare-transparenta-pentru-acces-usor-m2-m3-m4-m5-pentru-ma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 | 1 | 83 | 83
17 | Filament Polymaker PolyTerra PLA Charcoal Black (negru)1kg | https://www.filamente3d.ro/filamente/filament-polymaker-polyterra-pla-charcoal-black-negru-1kg | 1 | 109 | 109
18 | Filament Polymaker PolyTerra PLA Lavender Purple (violet)1kg | https://www.filamente3d.ro/filamente/filament-polymaker-polyterra-pla-lavender-purple-violet-1kg | 1 | 109 | 109
Ustensile Rare: | Imprimanta 3d (Bambulab A1 Mini) | Obligatoriu
 | Dezizolator | Optional (se poate folosi cel din setul de fire)
 | Cablu mini Hdmi | Optional (Se poate folosi un laptop cu ethernet)
Ustensile Comune: | Kit surubelnite | Obligatoriu
 | Cleste | Optional (Procesul de montare devine mai dificil)
 | Tastatura si Mouse wireless | Optional (Se poate folosi un laptop cu ethernet)

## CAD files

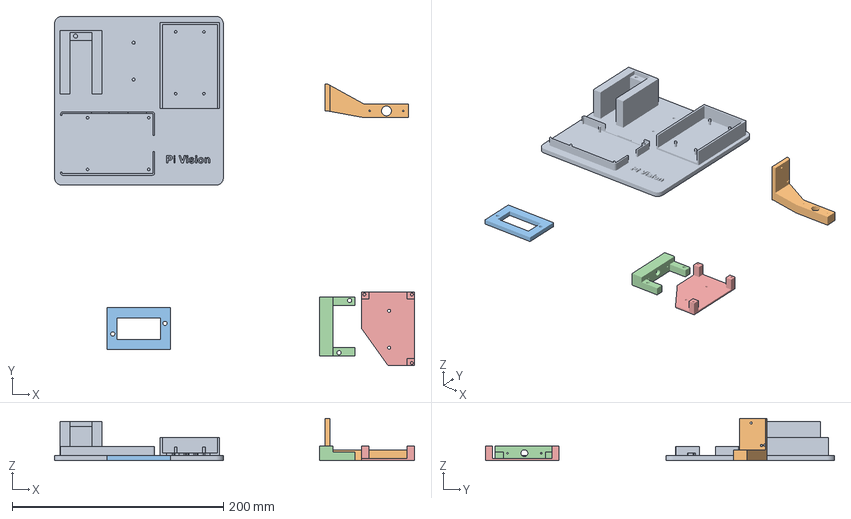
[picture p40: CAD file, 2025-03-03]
3mf sliced/Pi Vision.3mf
341.1 x 331.0 x 40.0 mm
Plate @.stl
Camera arm.stl
Servo 0 top bracket.stl
Servo 1 bracket.stl
Bracket pcb.stl

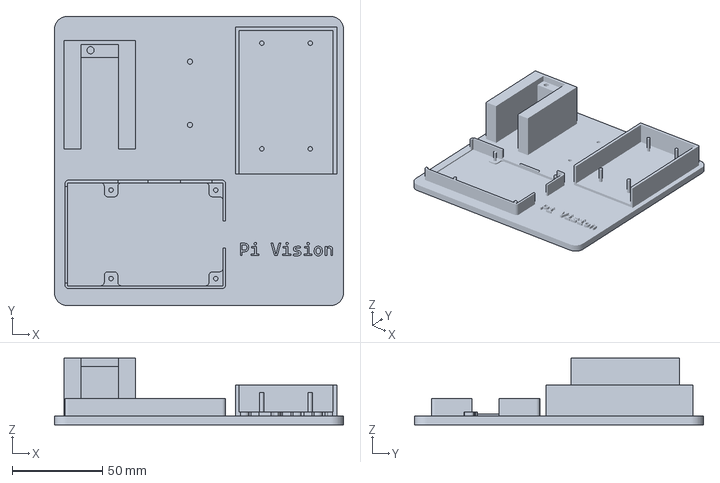
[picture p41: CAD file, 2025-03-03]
f3d/Base plate 2.3mf
160.0 x 160.0 x 37.0 mm

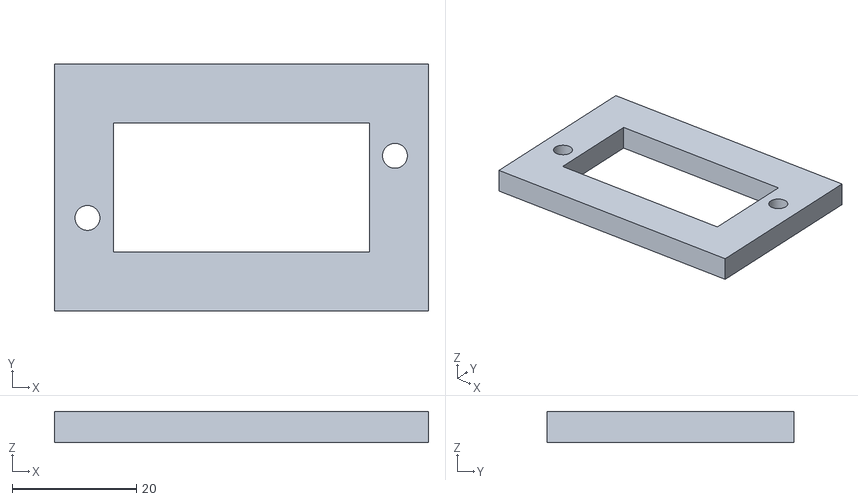
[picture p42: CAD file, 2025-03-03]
Stl/Servo 0 top bracket.stl
60.2 x 39.8 x 5.00

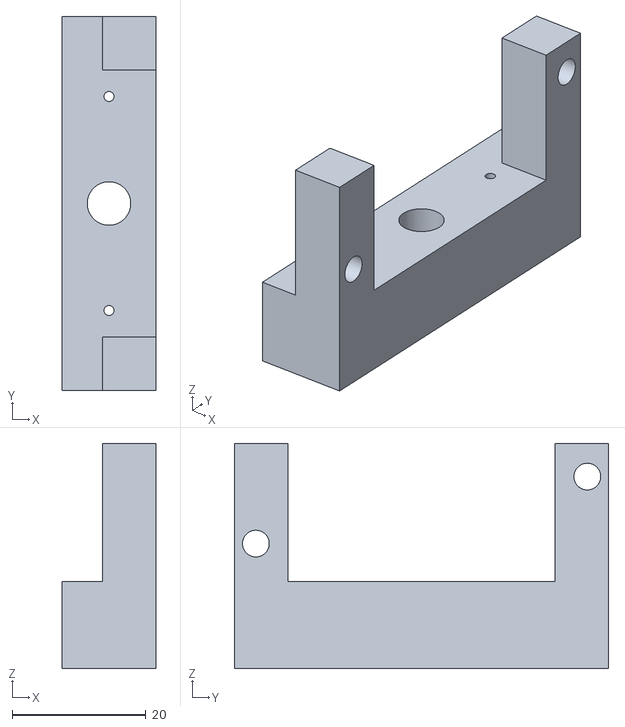
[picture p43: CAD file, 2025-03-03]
Stl/Servo 1 bracket.stl
14.0 x 56.0 x 33.7

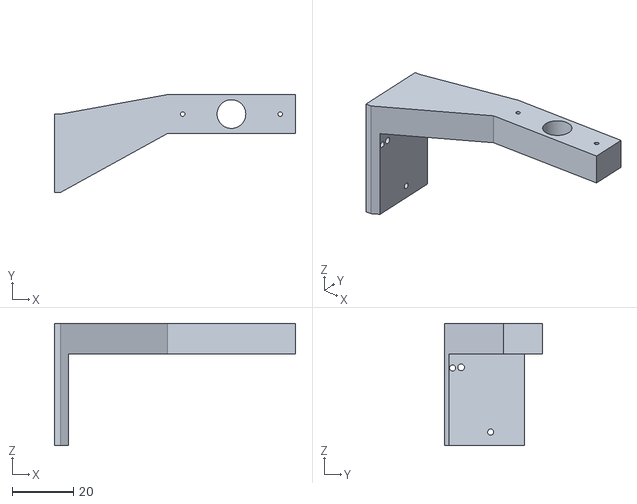
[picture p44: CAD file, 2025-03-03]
Stl/Camera arm.stl
79.0 x 32.1 x 40.0

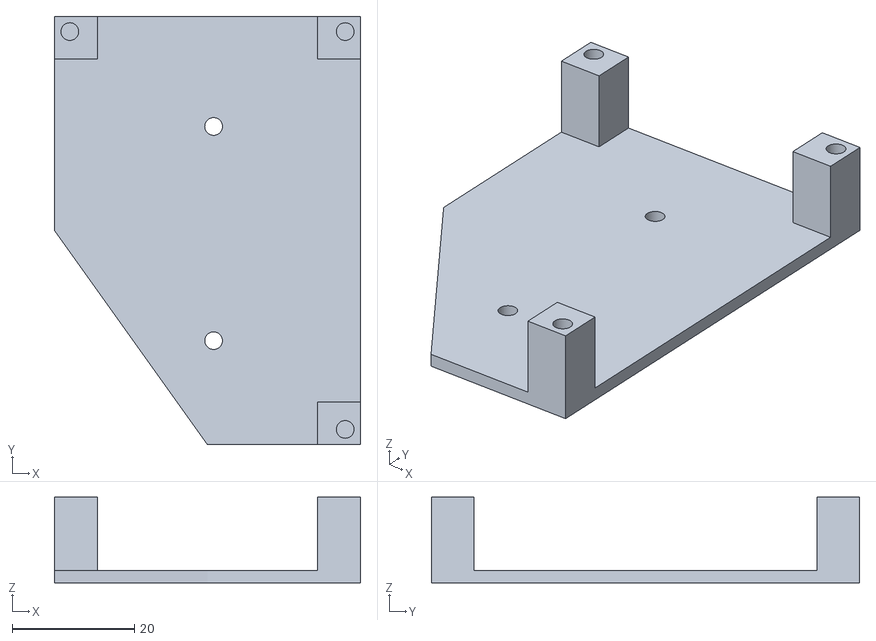
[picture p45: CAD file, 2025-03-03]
Stl/Bracket pcb.stl
50.0 x 70.0 x 14.0

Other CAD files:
Stl/Base Plate.stl
f3d/base plate.f3d
f3d/bracket pcb.f3d
f3d/camera arm.f3d
f3d/servo 0 top bracket.f3d
f3d/servo 1 bracket.f3d

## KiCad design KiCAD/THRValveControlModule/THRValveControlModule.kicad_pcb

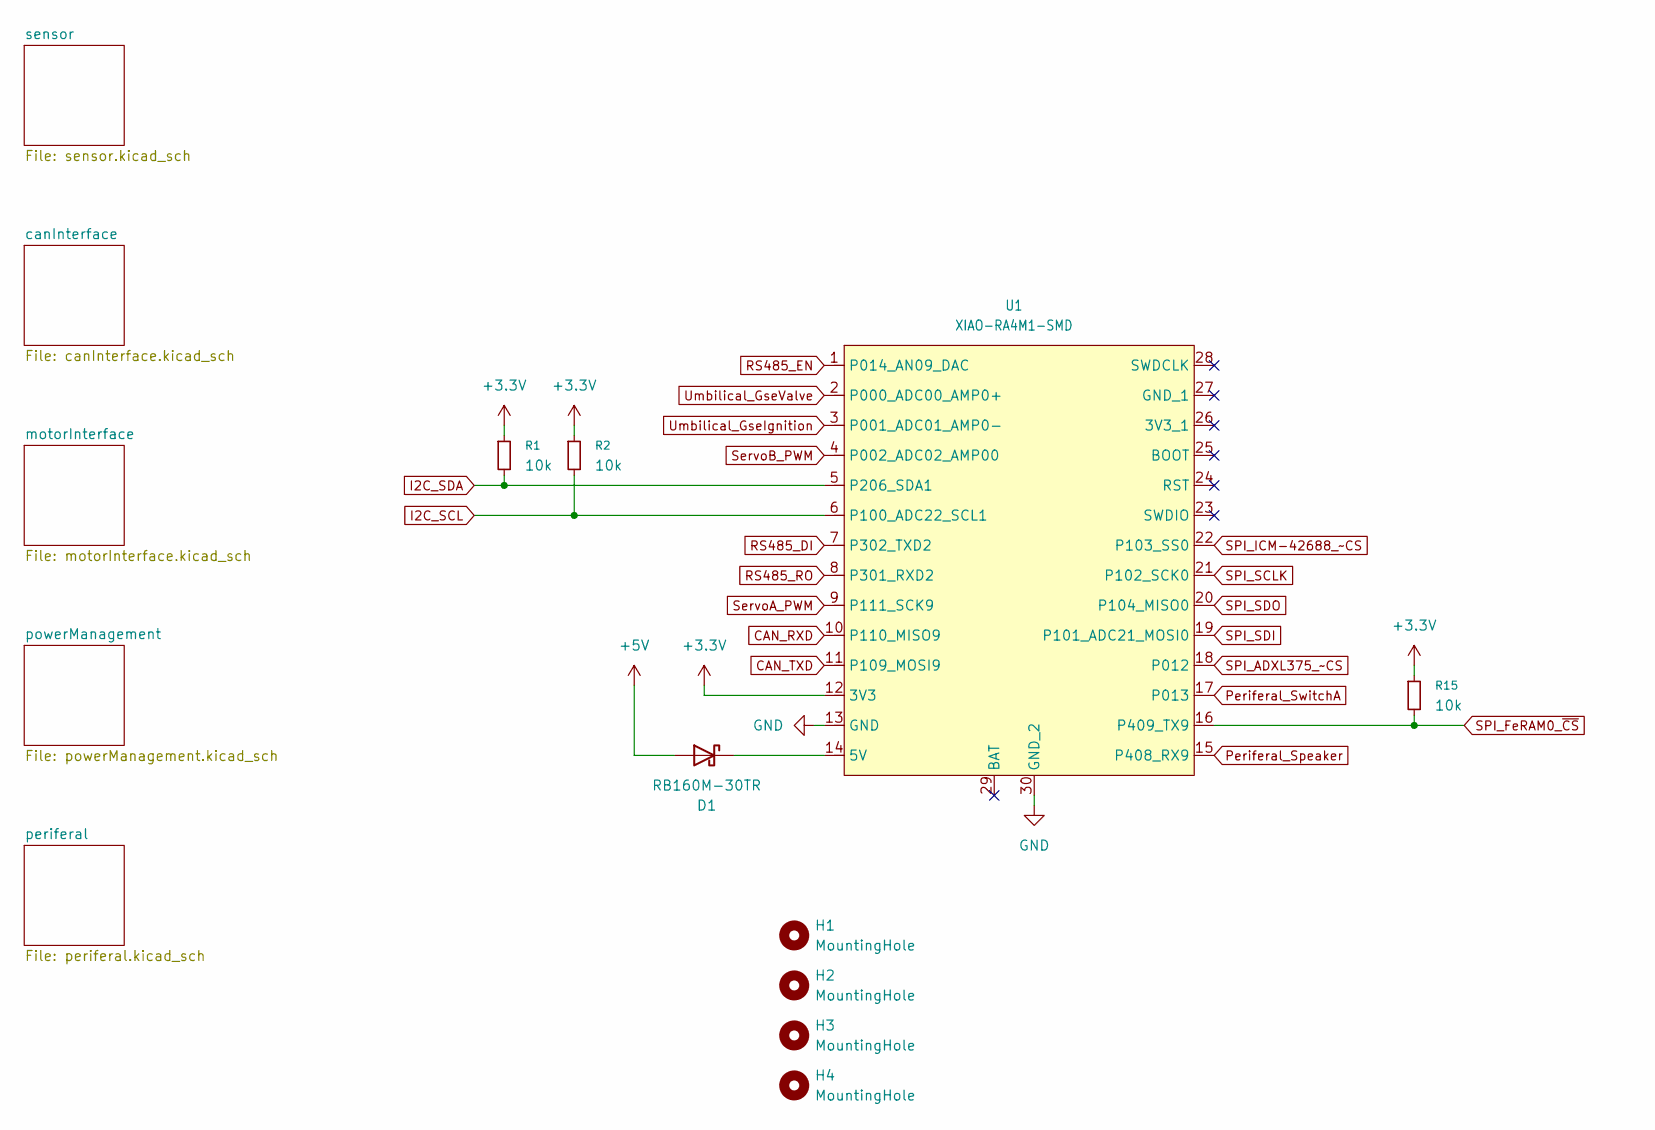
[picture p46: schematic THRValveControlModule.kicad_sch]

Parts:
D1: RB160M-30TR; D_SOD-123
H1, H2, H3, H4: MountingHole; MountingHole_3.2mm_M3_Pad_Via
R1, R2, R15: 10k; R_0603_1608Metric_Pad0.98x0.95mm_HandSolder
U1: XIAO-RA4M1-SMD

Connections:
+3.3V: R1.1, R2.1, R15.1, U1.12 (3V3); also elsewhere on the board
+5V: D1.2 (A); also elsewhere on the board
CAN_RXD: U1.10 (P110_MISO9); also elsewhere on the board
CAN_TXD: U1.11 (P109_MOSI9); also elsewhere on the board
GND: U1.13 (GND), U1.30 (GND_2); also elsewhere on the board
I2C_SCL: R2.2, U1.6 (P100_ADC22_SCL1); also elsewhere on the board
I2C_SDA: R1.2, U1.5 (P206_SDA1); also elsewhere on the board
unnamed: D1.1 (K), U1.14 (5V)
Periferal_Speaker: U1.15 (P408_RX9); also elsewhere on the board
Periferal_SwitchA: U1.17 (P013); also elsewhere on the board
RS485_DI: U1.7 (P302_TXD2); also elsewhere on the board
RS485_EN: U1.1 (P014_AN09_DAC); also elsewhere on the board
RS485_RO: U1.8 (P301_RXD2); also elsewhere on the board
SPI_ADXL375_~CS: U1.18 (P012); also elsewhere on the board
SPI_FeRAM0_~CS: R15.2, U1.16 (P409_TX9); also elsewhere on the board
SPI_ICM-42688_~CS: U1.22 (P103_SS0); also elsewhere on the board
SPI_SCLK: U1.21 (P102_SCK0); also elsewhere on the board
SPI_SDI: U1.19 (P101_ADC21_MOSI0); also elsewhere on the board
SPI_SDO: U1.20 (P104_MISO0); also elsewhere on the board
ServoA_PWM: U1.9 (P111_SCK9); also elsewhere on the board
ServoB_PWM: U1.4 (P002_ADC02_AMP00); also elsewhere on the board
Umbilical_GseIgnition: U1.3 (P001_ADC01_AMP0-); also elsewhere on the board
Umbilical_GseValve: U1.2 (P000_ADC00_AMP0+); also elsewhere on the board

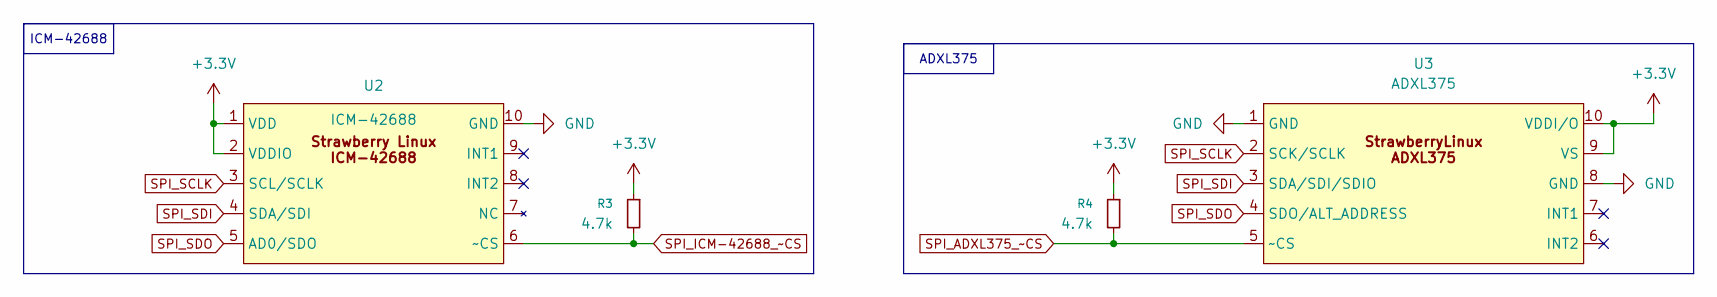
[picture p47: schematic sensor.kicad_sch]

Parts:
R3, R4: 4.7k; R_0603_1608Metric_Pad0.98x0.95mm_HandSolder
U2: ICM-42688; StrawberryLinux_ICM-42688-P
U3: ADXL375; StrawberryLinux_ADXL375

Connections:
+3.3V: R3.1, R4.1, U2.1 (VDD), U2.2 (VDDIO), U3.9 (VS), U3.10 (VDDI/O); also elsewhere on the board
GND: U2.10 (GND), U3.1 (GND), U3.8 (GND); also elsewhere on the board
SPI_ADXL375_~CS: R4.2, U3.5 (~CS); also elsewhere on the board
SPI_ICM-42688_~CS: R3.2, U2.6 (~CS); also elsewhere on the board
SPI_SCLK: U2.3 (SCL/SCLK), U3.2 (SCK/SCLK); also elsewhere on the board
SPI_SDI: U2.4 (SDA/SDI), U3.3 (SDA/SDI/SDIO); also elsewhere on the board
SPI_SDO: U2.5 (AD0/SDO), U3.4 (SDO/ALT_ADDRESS); also elsewhere on the board

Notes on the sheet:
ICM-42688
ADXL375

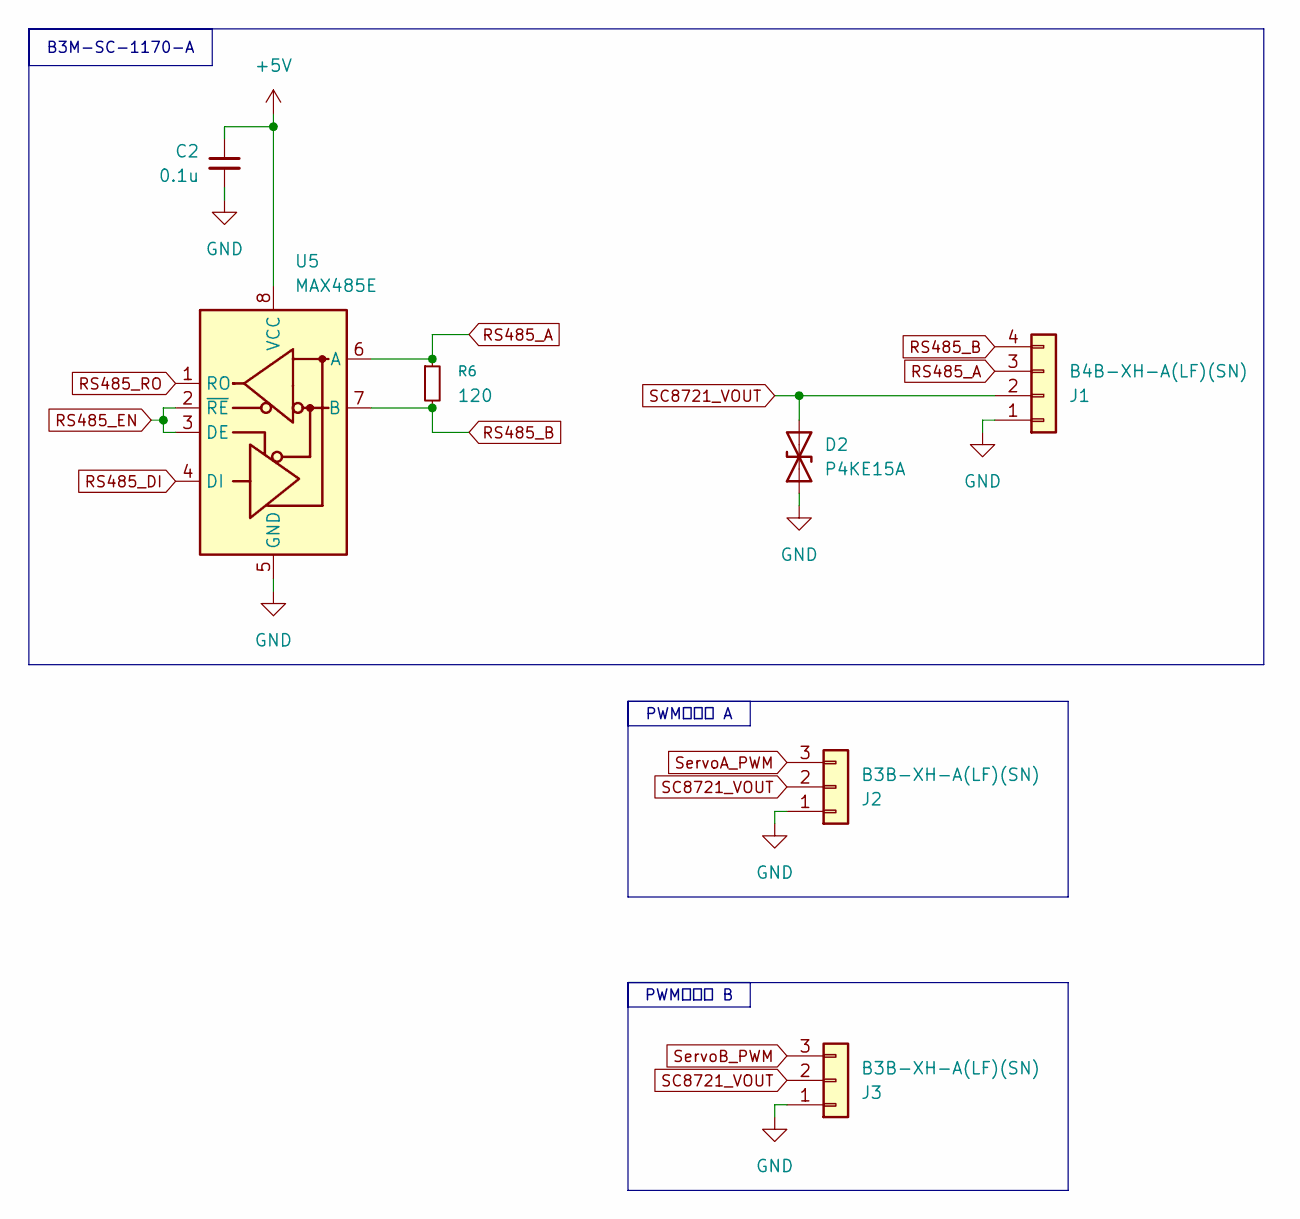
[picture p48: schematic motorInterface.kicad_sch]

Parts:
C2: 0.1u; C_0603_1608Metric_Pad1.08x0.95mm_HandSolder
D2: P4KE15A; D_DO-41_SOD81_P2.54mm_Vertical_KathodeUp
J1: B4B-XH-A(LF)(SN); JST_XH_B4B-XH-A_1x04_P2.50mm_Vertical
J2, J3: B3B-XH-A(LF)(SN); JST_XH_B3B-XH-A_1x03_P2.50mm_Vertical
R6: 120; R_0603_1608Metric_Pad0.98x0.95mm_HandSolder
U5: MAX485E; SOIC-8_3.9x4.9mm_P1.27mm

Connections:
+5V: C2.1, U5.8 (VCC); also elsewhere on the board
GND: C2.2, D2.1 (A1), J1.1, J2.1, J3.1, U5.5 (GND); also elsewhere on the board
RS485_A: J1.3, R6.1, U5.6 (A)
RS485_B: J1.4, R6.2, U5.7 (B)
RS485_DI: U5.4 (DI); also elsewhere on the board
RS485_EN: U5.2 (~RE), U5.3 (DE); also elsewhere on the board
RS485_RO: U5.1 (RO); also elsewhere on the board
SC8721_VOUT: D2.2 (A2), J1.2, J2.2, J3.2; also elsewhere on the board
ServoA_PWM: J2.3; also elsewhere on the board
ServoB_PWM: J3.3; also elsewhere on the board

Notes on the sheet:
PWMサーボ A
PWMサーボ B
B3M-SC-1170-A

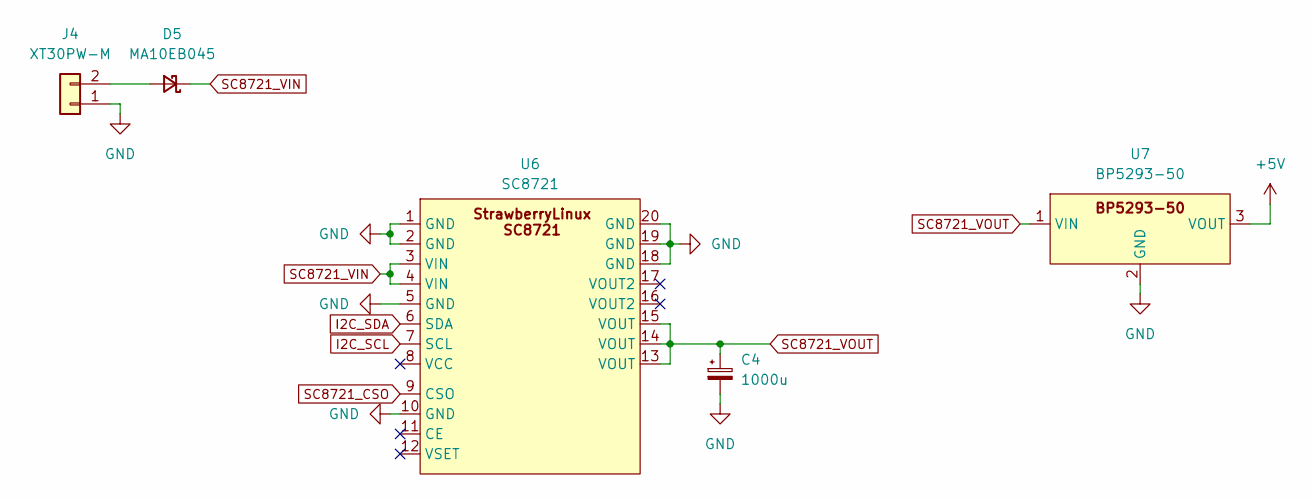
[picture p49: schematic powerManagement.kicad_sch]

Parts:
C4: 1000u; CP_Radial_D12.5mm_P5.00mm
D5: MA10EB045; MA_DO-221BC
J4: XT30PW-M; AMASS_XT30PW-M_1x02_P2.50mm_Horizontal
U6: SC8721; StrawberryLinux_SC8721
U7: BP5293-50

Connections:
+5V: U7.3 (VOUT); also elsewhere on the board
GND: C4.2, J4.1, U6.1 (GND), U6.2 (GND), U6.5 (GND), U6.10 (GND), U6.18 (GND), U6.19 (GND), U6.20 (GND), U7.2 (GND); also elsewhere on the board
I2C_SCL: U6.7 (SCL); also elsewhere on the board
I2C_SDA: U6.6 (SDA); also elsewhere on the board
unnamed: D5.2 (A), J4.2
SC8721_CSO: U6.9 (CSO)
SC8721_VIN: D5.1 (K), U6.3 (VIN), U6.4 (VIN)
SC8721_VOUT: C4.1, U6.13 (VOUT), U6.14 (VOUT), U6.15 (VOUT), U7.1 (VIN); also elsewhere on the board

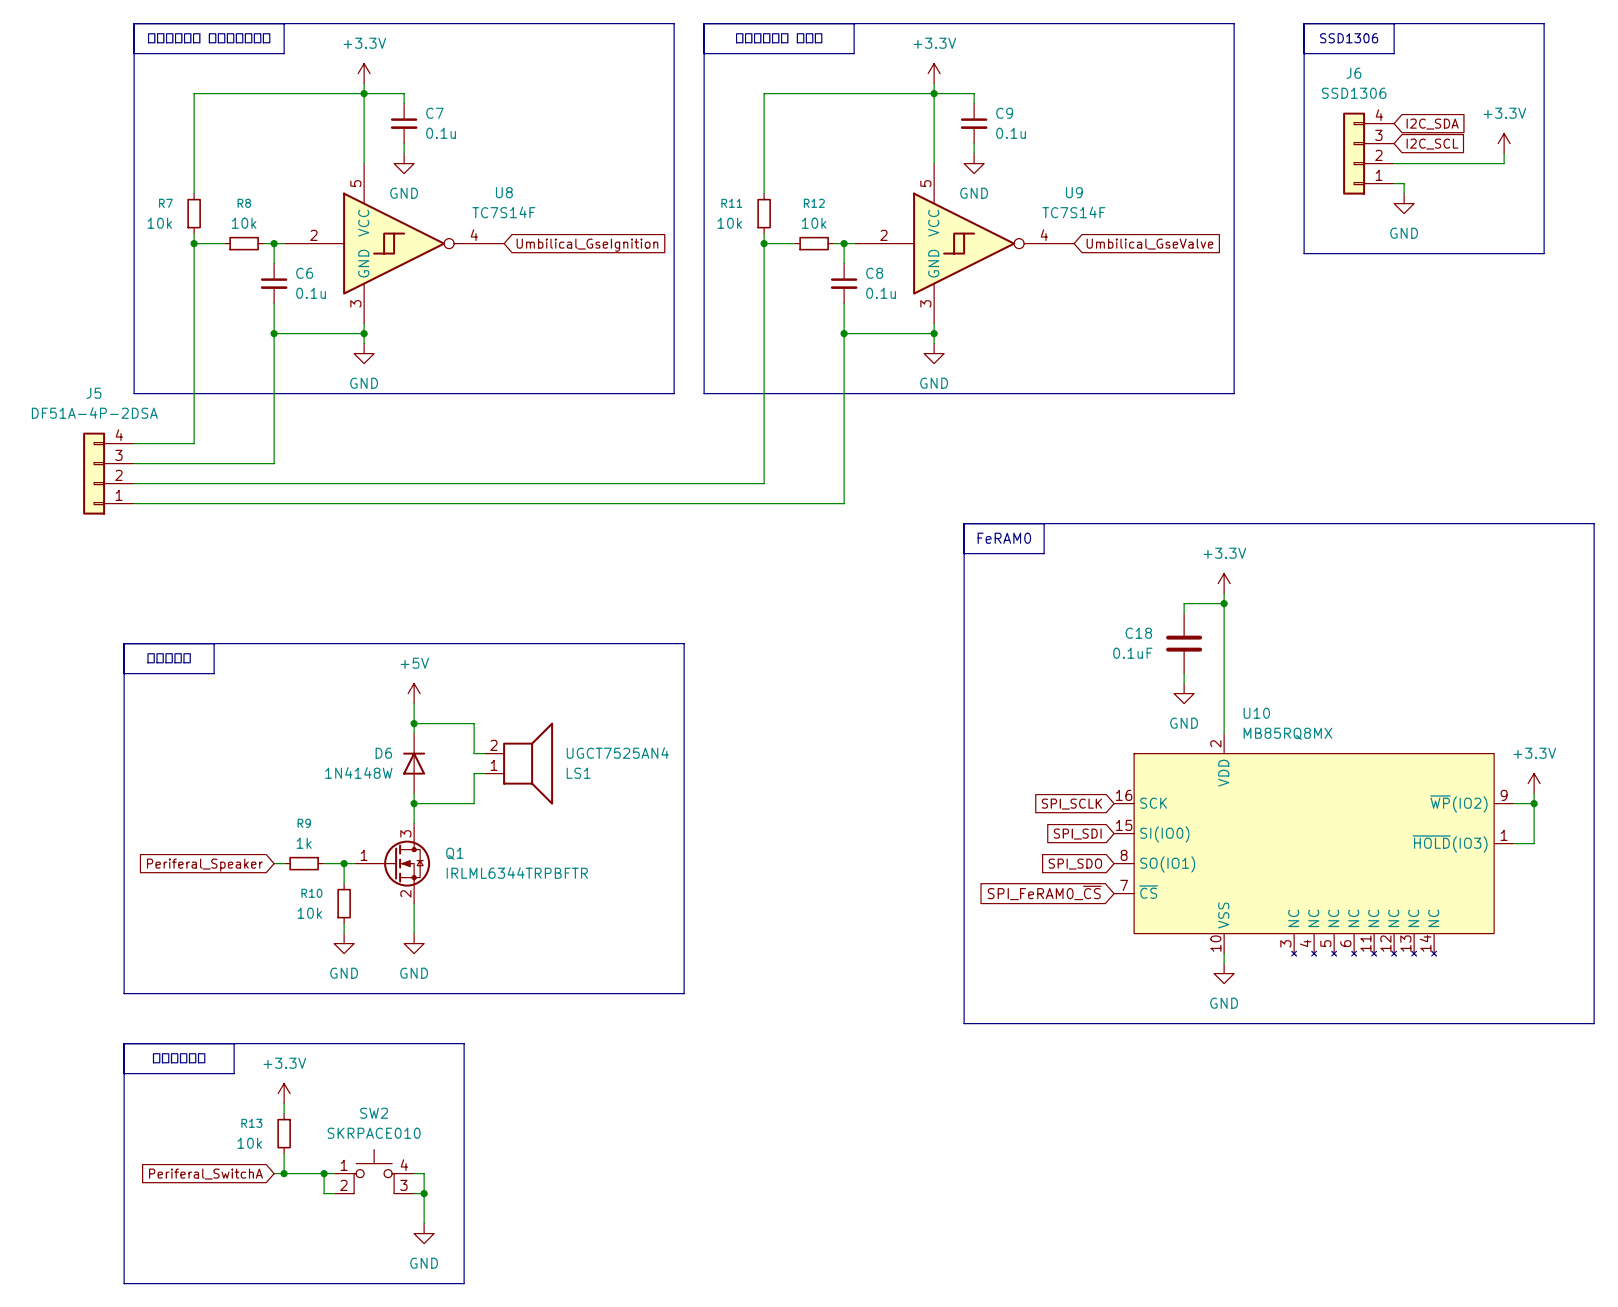
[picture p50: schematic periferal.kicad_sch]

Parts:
C6, C7, C8, C9: 0.1u; C_0603_1608Metric_Pad1.08x0.95mm_HandSolder
C18: 0.1uF; C_0603_1608Metric_Pad1.08x0.95mm_HandSolder
D6: 1N4148W; D_SOD-123
J5: DF51A-4P-2DSA
J6: SSD1306; PinHeader_1x04_P2.54mm_Vertical
LS1: UGCT7525AN4
Q1: IRLML6344TRPBFTR; SOT-23_Handsoldering
R7, R8, R10, R11, R12, R13: 10k; R_0603_1608Metric_Pad0.98x0.95mm_HandSolder
R9: 1k; R_0603_1608Metric_Pad0.98x0.95mm_HandSolder
SW2: SKRPACE010
U8, U9: TC7S14F; SOT-23-5
U10: MB85RQ8MX; SOIC-16W_7.5x10.3mm_P1.27mm

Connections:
+3.3V: C7.1, C9.1, C18.1, J6.2, R7.2, R11.2, R13.1, U8.5 (VCC), U9.5 (VCC), U10.1 (~HOLD(IO3)), U10.2 (VDD), U10.9 (~WP(IO2)); also elsewhere on the board
+5V: D6.1 (K), LS1.2; also elsewhere on the board
GND: C6.2, C7.2, C8.2, C9.2, C18.2, J5.1, J5.3, J6.1, Q1.2 (S), R10.1, SW2.3 (K), SW2.4 (A), U8.3 (GND), U9.3 (GND), U10.10 (VSS); also elsewhere on the board
I2C_SCL: J6.3; also elsewhere on the board
I2C_SDA: J6.4; also elsewhere on the board
unnamed: C6.1, R8.2, U8.2
unnamed: C8.1, R12.2, U9.2
unnamed: D6.2 (A), LS1.1, Q1.3 (D)
unnamed: J5.2, R11.1, R12.1
unnamed: J5.4, R7.1, R8.1
unnamed: Q1.1 (G), R9.1, R10.2
Periferal_Speaker: R9.2; also elsewhere on the board
Periferal_SwitchA: R13.2, SW2.1, SW2.2; also elsewhere on the board
SPI_FeRAM0_~CS: U10.7 (~CS); also elsewhere on the board
SPI_SCLK: U10.16 (SCK); also elsewhere on the board
SPI_SDI: U10.15 (SI(IO0)); also elsewhere on the board
SPI_SDO: U10.8 (SO(IO1)); also elsewhere on the board
Umbilical_GseIgnition: U8.4; also elsewhere on the board
Umbilical_GseValve: U9.4; also elsewhere on the board

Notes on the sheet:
アンビリカル イグニッション
SSD1306
アンビリカル バルブ
FeRAM0
ユーザー入力
スピーカー

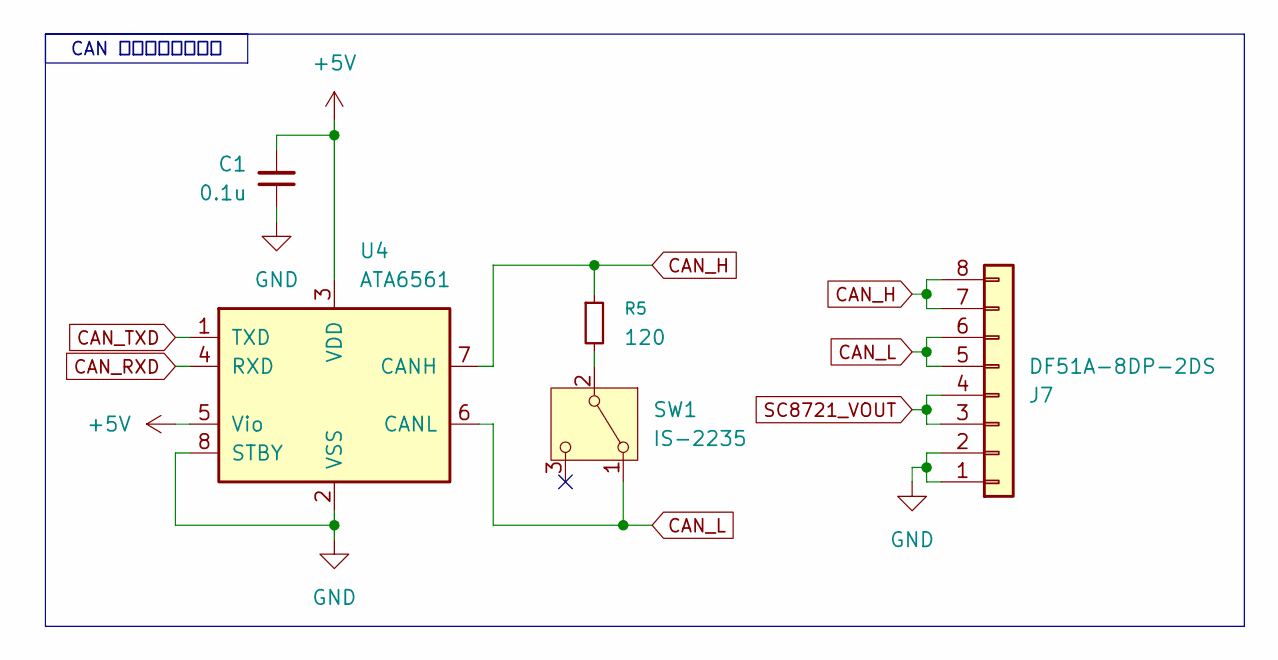
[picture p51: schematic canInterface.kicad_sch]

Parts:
C1: 0.1u; C_0603_1608Metric_Pad1.08x0.95mm_HandSolder
J7: DF51A-8DP-2DS
R5: 120; R_0603_1608Metric_Pad0.98x0.95mm_HandSolder
SW1: IS-2235; SW_CK_JS202011CQN_DPDT_Straight
U4: ATA6561; SOIC-8_3.9x4.9mm_P1.27mm

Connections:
+5V: C1.2, U4.3 (VDD), U4.5 (Vio); also elsewhere on the board
CAN_H: J7.7, J7.8, R5.1, U4.7 (CANH)
CAN_L: J7.5, J7.6, SW1.1 (A), U4.6 (CANL); also elsewhere on the board
CAN_RXD: U4.4 (RXD); also elsewhere on the board
CAN_TXD: U4.1 (TXD); also elsewhere on the board
GND: C1.1, J7.1, J7.2, U4.2 (VSS), U4.8 (STBY); also elsewhere on the board
unnamed 17: R5.2, SW1.2 (B); also elsewhere on the board
SC8721_VOUT: J7.3, J7.4; also elsewhere on the board

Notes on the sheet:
CAN インターフェース

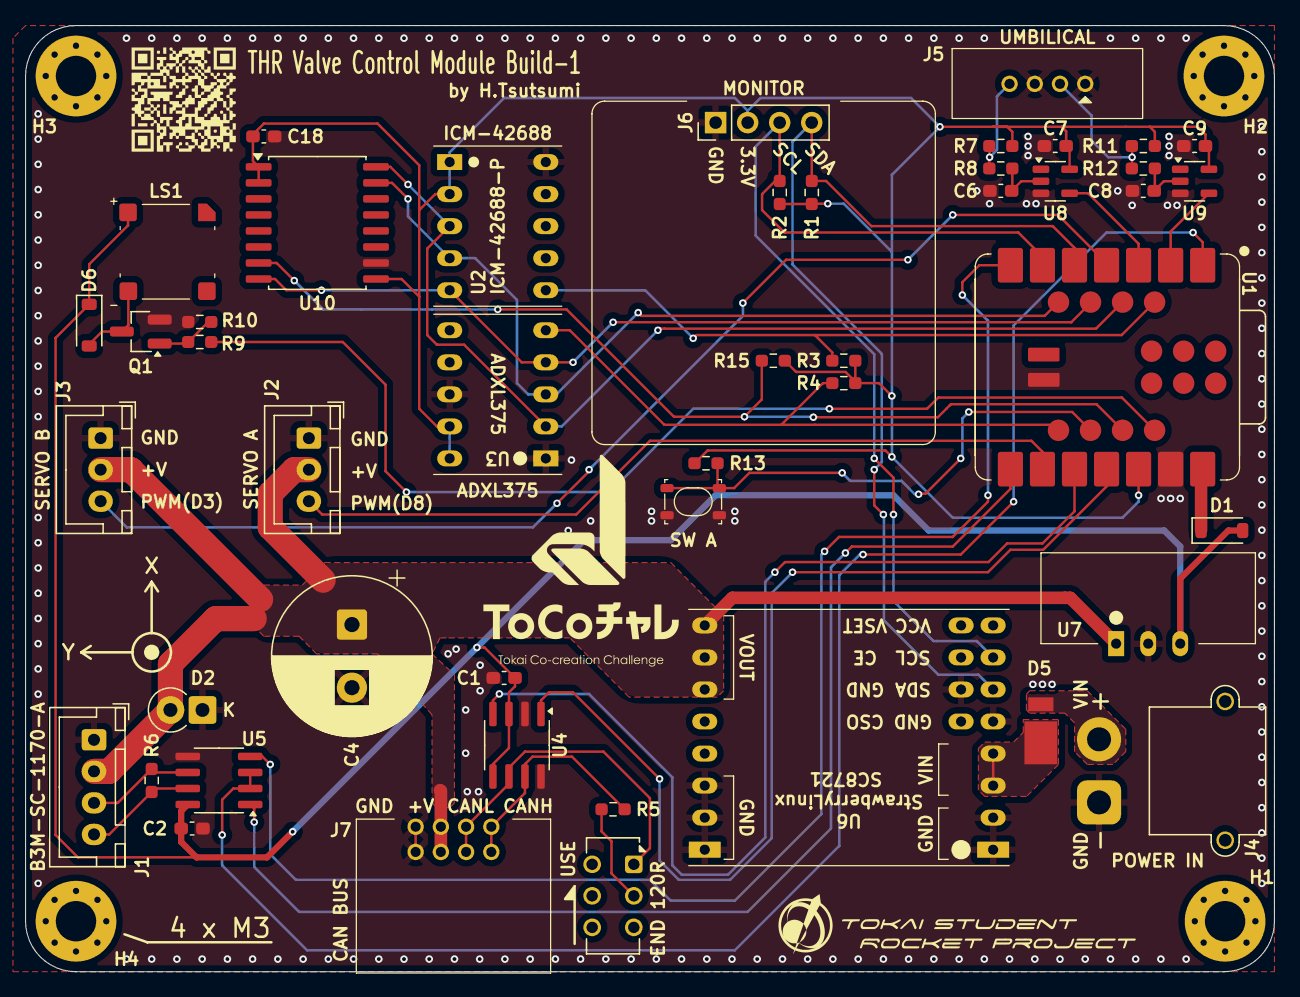
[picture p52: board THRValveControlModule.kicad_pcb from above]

Board: 2 copper layers, 99.0 x 75.0 mm, 51 parts (0 on the bottom side), 37 nets.

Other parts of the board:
END 120R: IS-2235; SW_CK_JS202011CQN_DPDT_Straight
SW A: SKRPACE010

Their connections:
CAN_L: END 120R.1 (A); also elsewhere on the board
GND: SW A.3 (K), SW A.4 (A); also elsewhere on the board
unnamed 17: END 120R.2 (B); also elsewhere on the board
Periferal_SwitchA: SW A.1, SW A.2; also elsewhere on the board

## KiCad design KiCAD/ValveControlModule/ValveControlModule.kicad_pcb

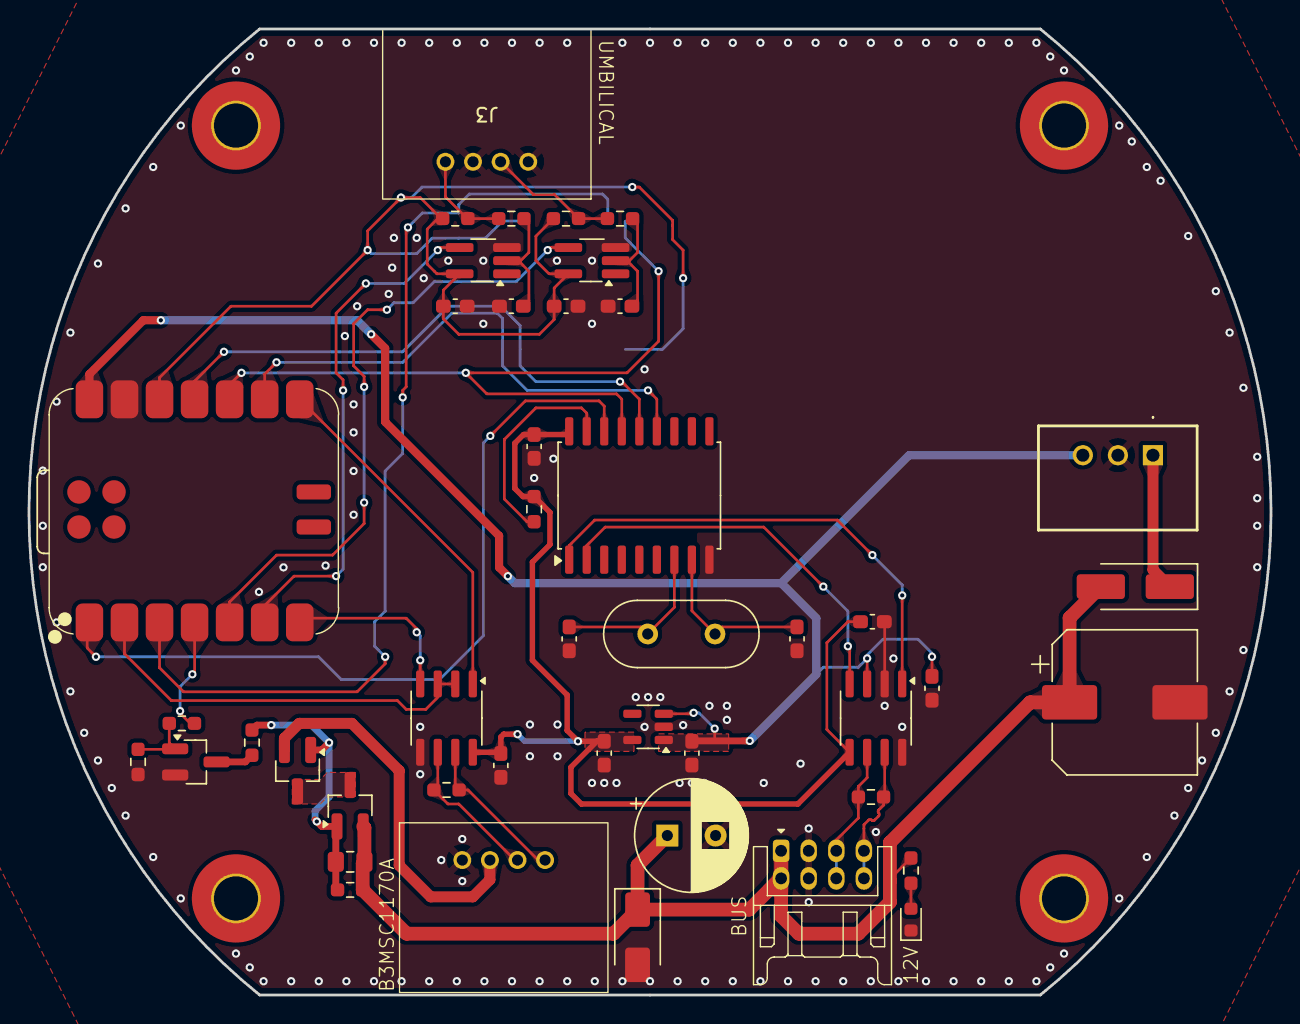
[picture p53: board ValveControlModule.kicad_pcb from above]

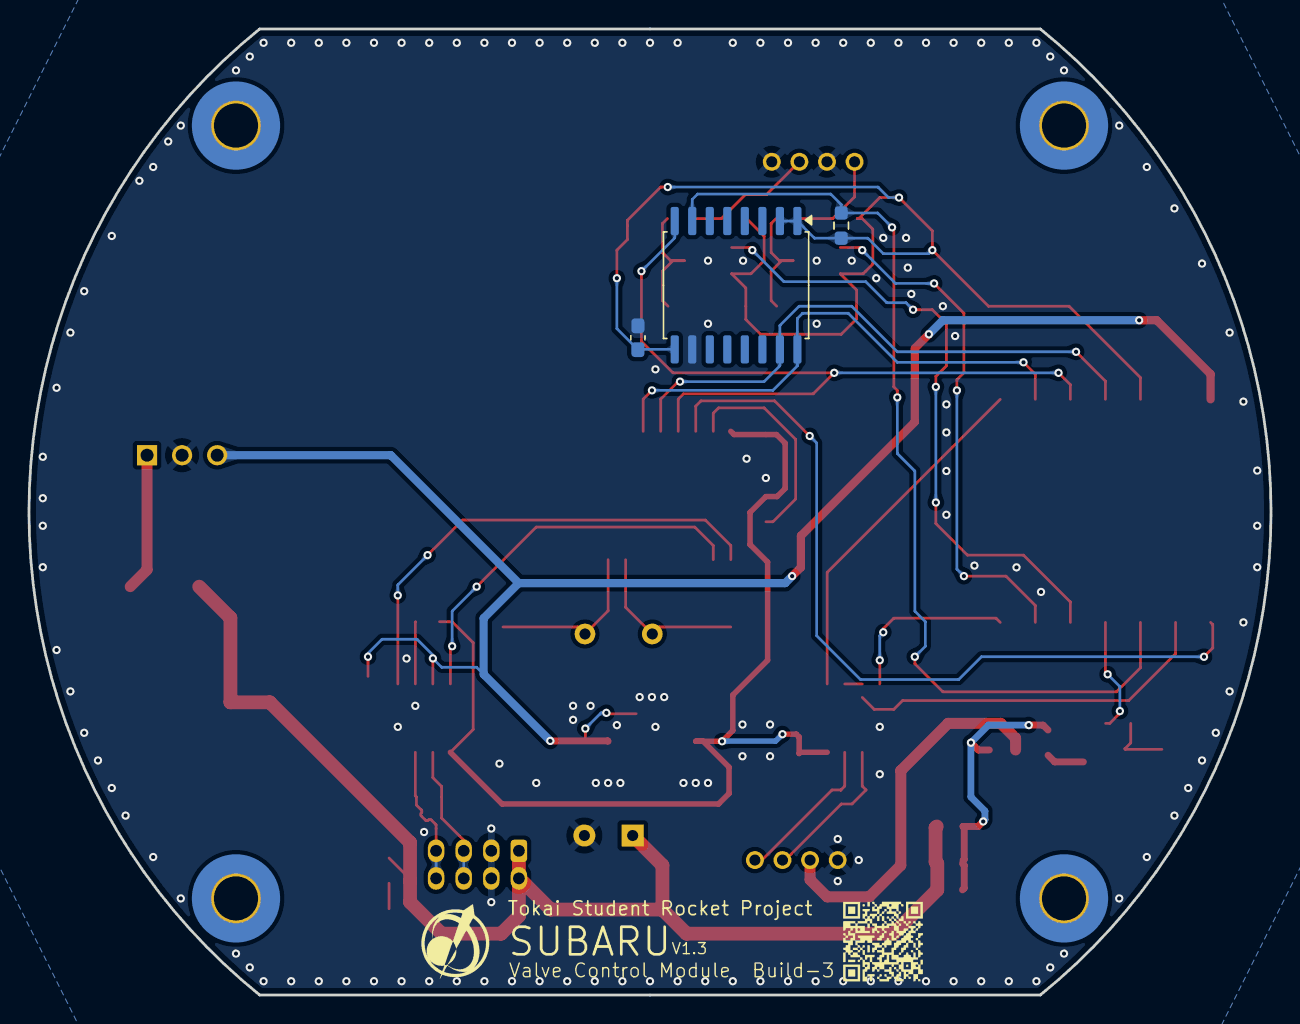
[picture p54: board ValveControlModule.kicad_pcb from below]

Board: 2 copper layers, 90.0 x 70.0 mm, 52 parts (3 on the bottom side), 36 nets.

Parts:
C1, C3, C4, C5, C11, C12, C13, C14, C18: 0.1uF; C_0603_1608Metric_Pad1.08x0.95mm_HandSolder
C6, C7: 15pF; C_0603_1608Metric_Pad1.08x0.95mm_HandSolder
C9, C10: 1uF; C_0603_1608Metric_Pad1.08x0.95mm_HandSolder
C15: 330uF; CP_Elec_10x10
C16: 100uF; CP_Radial_D8.0mm_P3.50mm
C17: 22uF; C_0805_2012Metric_Pad1.18x1.45mm_HandSolder
D1: SMAJ45A; D_SMA
D3: Green; LED_0603_1608Metric
D9: SB34AFC; D_SMA_Handsoldering
H1, H2, H3, H4: MountingHole_Pad; MountingHole_3.2mm_M3_Pad_TopBottom
J1, J3: DF51A-4P-2DS
J2: DF11-8DP-2DS
PS1: M78AR05-0.5; M78AR03305
Q2, Q4: AO3401A; SOT-23_Handsoldering
Q3: AO3400A; SOT-23_Handsoldering
R1, R6: 120; R_0603_1608Metric_Pad0.98x0.95mm_HandSolder
R4: 10K; R_0603_1608Metric_Pad0.98x0.95mm_HandSolder
R9: 4.7k; R_0603_1608Metric_Pad0.98x0.95mm_HandSolder
R10: 820R; R_0603_1608Metric_Pad0.98x0.95mm_HandSolder
R11: 2.4kR; R_0603_1608Metric_Pad0.98x0.95mm_HandSolder
R12, R14, R24, R25, R26, R27: 10kR; R_0603_1608Metric_Pad0.98x0.95mm_HandSolder
R13: 100kR; R_0603_1608Metric_Pad0.98x0.95mm_HandSolder
U1: XIAO-RP2040-DIP; XIAO-RP2040-SMD
U2: LT1785xS8; SOIC-8_3.9x4.9mm_P1.27mm
U3: MCP2515-xSO; SOIC-18W_7.5x11.6mm_P1.27mm
U4: MCP2562-E-SN; SOIC-8_3.9x4.9mm_P1.27mm
U5: NCV8114BSN330T1G; TSOT-23-5
U6: MB85RQ8MX; SOIC-16W_7.5x10.3mm_P1.27mm
U8, U9: TC7S14F; TSOT-23-5_HandSoldering
Y1: 8MHz; Crystal_HC49-4H_Vertical

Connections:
+3.3V: C1.2, C3.1, C5.2, C10.1, R4.2, U2.8 (VCC), U3.18 (VDD), U4.5 (Vio), U5.5 (OUT)
+3V3: C12.2, C14.2, C18.1, R9.1, R24.2, R26.2, U1.12 (3V3), U6.1 (~HOLD(IO3)), U6.2 (VDD), U6.9 (~WP(IO2)), U8.5 (VCC), U9.5 (VCC)
+5V: C4.2, C9.1, PS1.3 (+VOUT), U1.14 (VBUS), U4.3 (VDD), U5.1 (IN), U5.3 (EN)
+12V: C15.1, C16.1, C17.1, D1.1 (K), D9.2 (A), J2.1, J2.2, Q4.2 (S), R11.1, R12.1
CAN_H: J2.7, J2.8, R6.2, U4.7 (CANH)
CAN_L: J2.5, J2.6, R6.1, U4.6 (CANL)
CAN_RX: U3.2 (RXCAN), U4.4 (RXD)
CAN_TX: U3.1 (TXCAN), U4.1 (TXD)
GND: C1.1, C3.2, C4.1, C5.1, C6.2, C7.2, C9.2, C10.2, C11.1, C12.1, C13.1, C14.1, C15.2, C16.2, C18.2, D1.2 (A), D3.1 (K), J1.1, J2.3, J2.4, J3.1, J3.3, PS1.2 (GND), Q3.2 (S), R14.2, U1.13 (GND), U2.5 (GND), U3.9 (VSS), U4.2 (VSS), U4.8 (STBY), U5.2 (GND), U6.10 (VSS), U8.3 (GND), U9.3 (GND)
unnamed: C11.2, R25.2, U8.2
unnamed: C13.2, R27.2, U9.2
unnamed: D3.2 (A), R11.2
unnamed: D9.1 (K), PS1.1 (+VIN)
unnamed: J1.2, Q2.2 (S)
unnamed: J3.2, R26.1, R27.1
unnamed: J3.4, R24.1, R25.1
unnamed: Q2.3 (D), Q4.3 (D)
unnamed: C17.2, Q2.1 (G), Q4.1 (G), R12.2, R13.1
unnamed: Q3.3 (D), R13.2
unnamed: Q3.1 (G), R10.2, R14.1
unnamed: R4.1, U3.17 (~RESET)
OSC1: C6.1, U3.8 (OSC1), Y1.2
OSC2: C7.1, U3.7 (OSC2), Y1.1
RS485_A: J1.3, R1.1, U2.6 (A)
RS485_B: J1.4, R1.2, U2.7 (B)
RS485_DI: U1.7 (GPIO0/TX), U2.4 (DI)
RS485_EN: U1.2 (GPIO27/ADC1/A1), U2.2 (~RE), U2.3 (DE)
RS485_RO: U1.8 (GPIO1/RX), U2.1 (RO)
SPI_CS_MCP2515: U1.1 (GPIO26/ADC0/A0), U3.16 (~CS)
SPI_MISO: U1.10 (GPIO4/MISO), U3.15 (SO), U6.8 (SO(IO1))
SPI_MOSI: U1.11 (GPIO3/MOSI), U3.14 (SI), U6.15 (SI(IO0))
SPI_SCK: U1.9 (GPIO2/SCK), U3.13 (SCK), U6.16 (SCK)
SPI_~CS_FeRAM0: R9.2, U1.3 (GPIO28/ADC2/A2), U6.7 (~CS)
ServoPower_EN: R10.1, U1.4 (GPIO29/ADC3/A3)
Umbilical_GseIgnition: U1.6 (GPIO7/SCL), U8.4
Umbilical_GseValve: U1.5 (GPIO6/SDA), U9.4

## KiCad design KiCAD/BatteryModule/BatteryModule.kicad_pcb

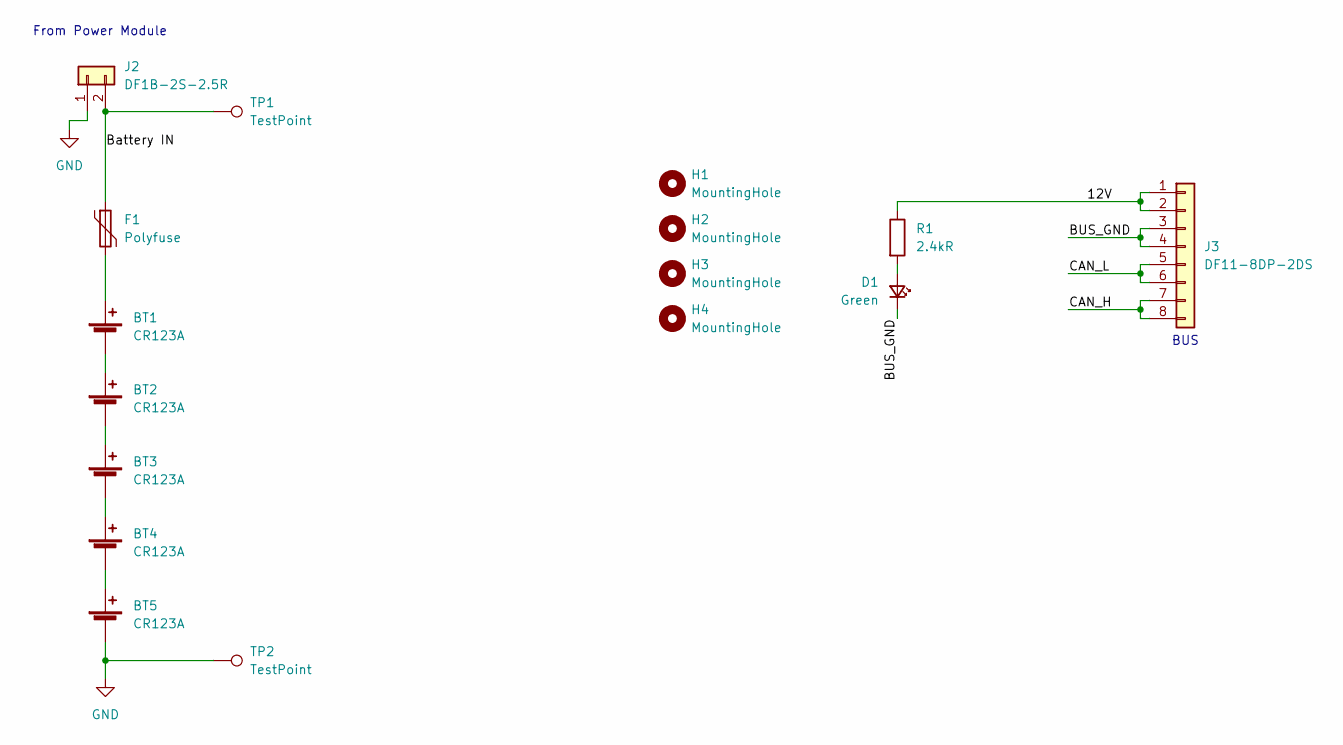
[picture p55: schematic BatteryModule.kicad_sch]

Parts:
BT1, BT2, BT3, BT4, BT5: CR123A; BHC-CR123A
D1: Green; LED_0603_1608Metric_Pad1.05x0.95mm_HandSolder
F1: Polyfuse; Fuse_Bourns_MF-RHT300
H1, H2, H3, H4: MountingHole; MountingHole_3.2mm_M3_Pad_TopBottom
J2: DF1B-2S-2.5R
J3: DF11-8DP-2DS
R1: 2.4kR; R_0603_1608Metric_Pad0.98x0.95mm_HandSolder
TP1, TP2: TestPoint; TestPoint_THTPad_D2.0mm_Drill1.0mm

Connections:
/12V: J3.1, J3.2, R1.1
/BUS_GND: D1.1 (K), J3.3, J3.4
/Battery IN: F1.1, J2.2, TP1.1
/CAN_H: J3.7, J3.8
/CAN_L: J3.5, J3.6
GND: BT5.2 (-), J2.1, TP2.1
unnamed: BT1.1 (+), F1.2
unnamed: BT1.2 (-), BT2.1 (+)
unnamed: BT2.2 (-), BT3.1 (+)
unnamed: BT3.2 (-), BT4.1 (+)
unnamed: BT4.2 (-), BT5.1 (+)
unnamed: D1.2 (A), R1.2

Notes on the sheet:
BUS
From Power Module

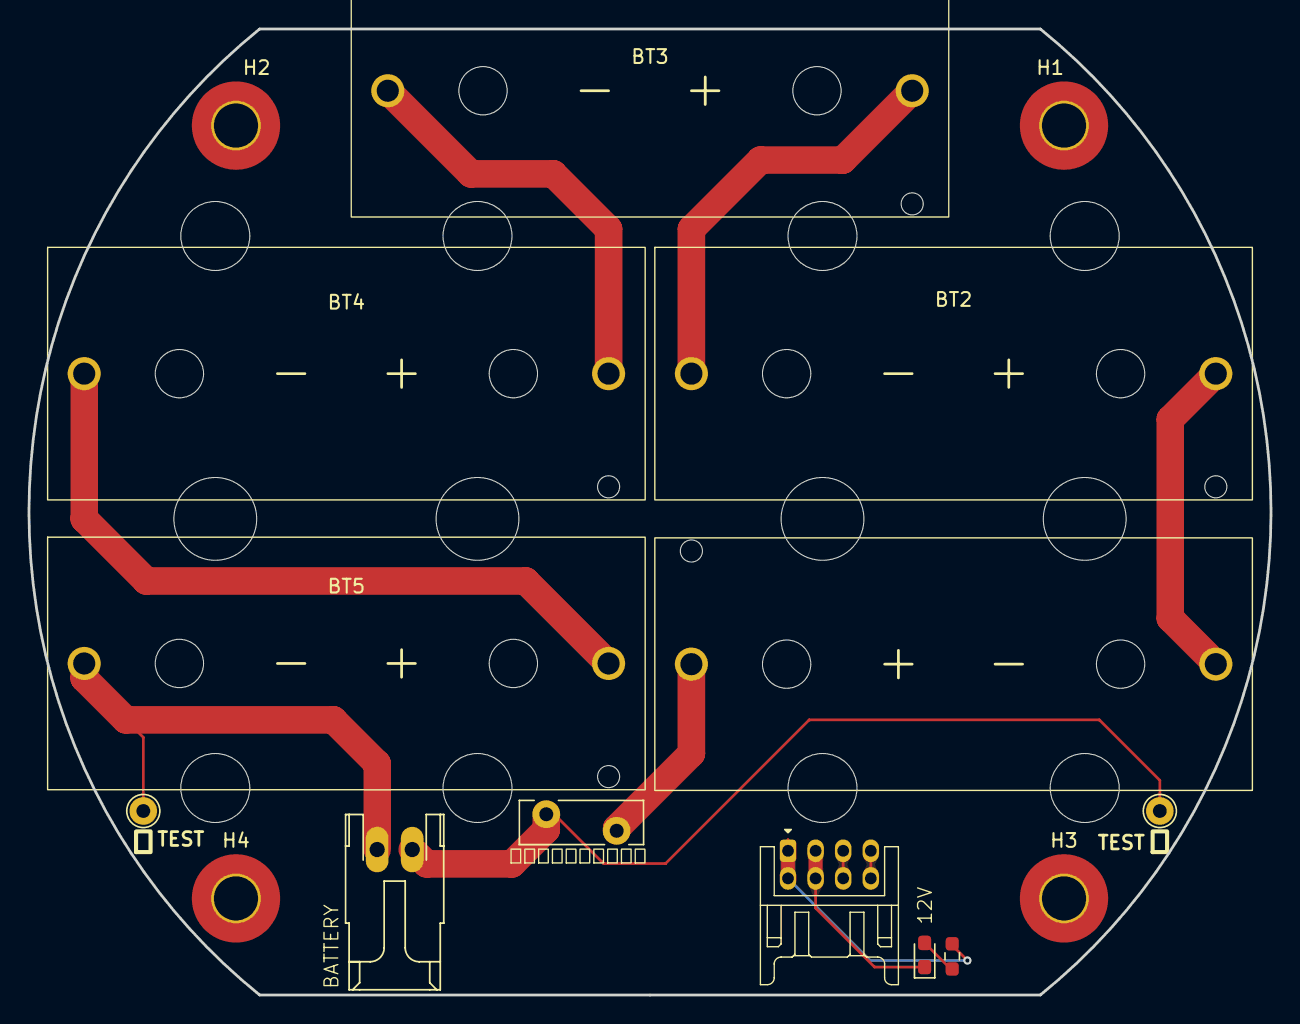
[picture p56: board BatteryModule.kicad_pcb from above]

Board: 2 copper layers, 90.0 x 70.0 mm, 16 parts (0 on the bottom side), 12 nets.

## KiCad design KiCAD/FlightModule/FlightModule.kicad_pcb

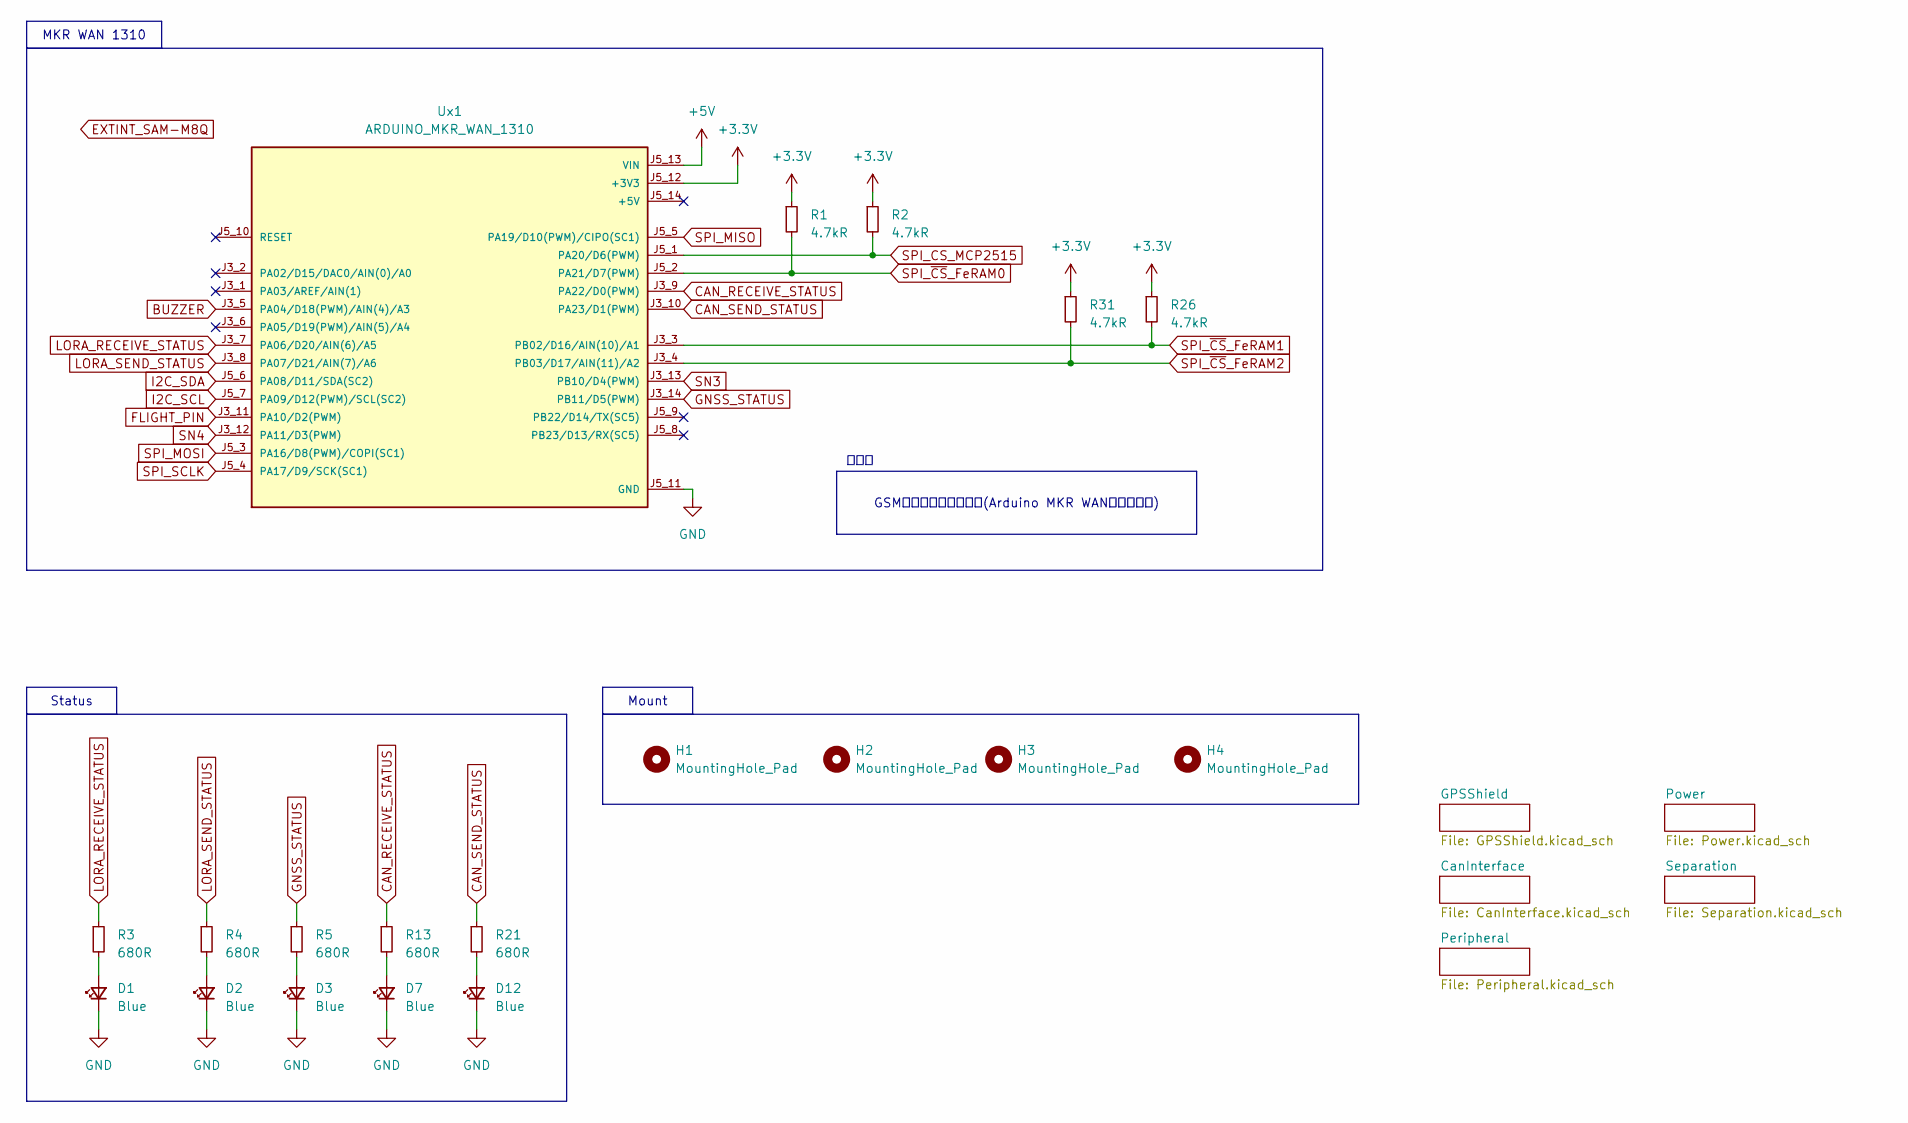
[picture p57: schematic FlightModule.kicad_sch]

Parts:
D1, D2, D3, D7, D12: Blue; LED_0603_1608Metric_Pad1.05x0.95mm_HandSolder
H1, H2, H3, H4: MountingHole_Pad; MountingHole_3.2mm_M3_Pad_TopBottom
R1, R2, R26, R31: 4.7kR; R_0603_1608Metric_Pad0.98x0.95mm_HandSolder
R3, R4, R5, R13, R21: 680R; R_0603_1608Metric_Pad0.98x0.95mm_HandSolder
Ux1: ARDUINO_MKR_WAN_1310; BOARD_ARDUINO_MKR_WAN_1310; PARTREV 06/27/2019

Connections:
+3.3V: R1.1, R2.1, R26.1, R31.1, Ux1.J5_12 (+3V3); also elsewhere on the board
+5V: Ux1.J5_13 (VIN); also elsewhere on the board
BUZZER: Ux1.J3_5 (PA04/D18(PWM)/AIN(4)/A3); also elsewhere on the board
CAN_RECEIVE_STATUS: R13.1, Ux1.J3_9 (PA22/D0(PWM))
CAN_SEND_STATUS: R21.1, Ux1.J3_10 (PA23/D1(PWM))
FLIGHT_PIN: Ux1.J3_11 (PA10/D2(PWM)); also elsewhere on the board
GND: D1.1 (K), D2.1 (K), D3.1 (K), D7.1 (K), D12.1 (K), Ux1.J5_11 (GND); also elsewhere on the board
GNSS_STATUS: R5.1, Ux1.J3_14 (PB11/D5(PWM))
I2C_SCL: Ux1.J5_7 (PA09/D12(PWM)/SCL(SC2)); also elsewhere on the board
I2C_SDA: Ux1.J5_6 (PA08/D11/SDA(SC2)); also elsewhere on the board
LORA_RECEIVE_STATUS: R3.1, Ux1.J3_7 (PA06/D20/AIN(6)/A5)
LORA_SEND_STATUS: R4.1, Ux1.J3_8 (PA07/D21/AIN(7)/A6)
unnamed: D1.2 (A), R3.2
unnamed: D2.2 (A), R4.2
unnamed: D3.2 (A), R5.2
unnamed: D7.2 (A), R13.2
unnamed: D12.2 (A), R21.2
SN3: Ux1.J3_13 (PB10/D4(PWM)); also elsewhere on the board
SN4: Ux1.J3_12 (PA11/D3(PWM)); also elsewhere on the board
SPI_CS_MCP2515: R2.2, Ux1.J5_1 (PA20/D6(PWM)); also elsewhere on the board
SPI_MISO: Ux1.J5_5 (PA19/D10(PWM)/CIPO(SC1)); also elsewhere on the board
SPI_MOSI: Ux1.J5_3 (PA16/D8(PWM)/COPI(SC1)); also elsewhere on the board
SPI_SCLK: Ux1.J5_4 (PA17/D9/SCK(SC1)); also elsewhere on the board
SPI_~CS_FeRAM0: R1.2, Ux1.J5_2 (PA21/D7(PWM)); also elsewhere on the board
SPI_~CS_FeRAM1: R26.2, Ux1.J3_3 (PB02/D16/AIN(10)/A1); also elsewhere on the board
SPI_~CS_FeRAM2: R31.2, Ux1.J3_4 (PB03/D17/AIN(11)/A2); also elsewhere on the board

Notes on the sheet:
付属品
GSMダイポールアンテナ(Arduino MKR WAN用アンテナ)
Mount
MKR WAN 1310
Status


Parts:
C1: 330uF; CP_Elec_10x10
C10, C11: 1uF; C_0805_2012Metric_Pad1.18x1.45mm_HandSolder
D4: Green; LED_0603_1608Metric_Pad1.05x0.95mm_HandSolder
D5: GS1010FL; D_SOD-123F
PS1: M78AR05-0.5; M78AR03305; Manufacturer_Part_Number M78AR05-0.5
R6: 2.4kR; R_0603_1608Metric_Pad0.98x0.95mm_HandSolder
U5: NCV8114BSN330T1G; TSOT-23-5

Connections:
+3.3V: C11.1, U5.5 (OUT); also elsewhere on the board
+5V: C10.1, PS1.3 (+VOUT), U5.1 (IN), U5.3 (EN); also elsewhere on the board
+12V: C1.1, D5.2 (A), R6.1; also elsewhere on the board
GND: C1.2, C10.2, C11.2, D4.1 (K), PS1.2 (GND), U5.2 (GND); also elsewhere on the board
unnamed: D4.2 (A), R6.2
unnamed: D5.1 (K), PS1.1 (+VIN)

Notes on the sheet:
本当は RT9080-33GJ5
Power Good
Linear Regulator
Switching Regulator
To MCU
From BUS
From DCDC


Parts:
C4, C5, C13: 0.1uF; C_0603_1608Metric_Pad1.08x0.95mm_HandSolder
C6, C7: 15pF; C_0603_1608Metric_Pad1.08x0.95mm_HandSolder
J1: DF11B-8DP-2DS; DF11-8DP-2DS
R11: 120R; R_0603_1608Metric_Pad0.98x0.95mm_HandSolder
R14: 10kR; R_0603_1608Metric_Pad0.98x0.95mm_HandSolder
U8: MCP2562-E-SN; SOIC-8_3.9x4.9mm_P1.27mm
U9: MCP2515-xST; TSSOP-20_4.4x6.5mm_P0.65mm
Y1: 8MHz; Crystal_SMD_HC49-SD

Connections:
+3.3V: C4.2, C5.2, R14.2, U8.5 (Vio), U9.20 (VDD); also elsewhere on the board
+5V: C13.2, U8.3 (VDD); also elsewhere on the board
+12V: J1.1, J1.2; also elsewhere on the board
CAN_H: J1.7, J1.8, R11.1, U8.7 (CANH)
CAN_L: J1.5, J1.6, R11.2, U8.6 (CANL)
CAN_RX: U8.4 (RXD), U9.2 (RXCAN)
CAN_TX: U8.1 (TXD), U9.1 (TXCAN)
GND: C4.1, C5.1, C6.2, C7.2, C13.1, J1.3, J1.4, U8.2 (VSS), U8.8 (STBY), U9.10 (VSS); also elsewhere on the board
unnamed: R14.1, U9.19 (~RESET)
OSC1: C6.1, U9.9 (OSC1), Y1.2
OSC2: C7.1, U9.8 (OSC2), Y1.1
SPI_CS_MCP2515: U9.18 (~CS); also elsewhere on the board
SPI_MISO: U9.17 (SO); also elsewhere on the board
SPI_MOSI: U9.16 (SI); also elsewhere on the board
SPI_SCLK: U9.14 (SCK); also elsewhere on the board

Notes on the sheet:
BUS：CAN + 電源ライン
組み立て位置により終端抵抗の 取り付けを有無を決めること
CANコントローラー
CANトランシーバー


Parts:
C16, C17: 1uF; C_0805_2012Metric_Pad1.18x1.45mm_HandSolder
R27: 100kR; R_0603_1608Metric_Pad0.98x0.95mm_HandSolder
R28: 0R; R_0603_1608Metric_Pad0.98x0.95mm_HandSolder
R29, R30: 4.7kR; R_0603_1608Metric_Pad0.98x0.95mm_HandSolder
U3: SAM-M8Q-0-10; MODULE_SAM-M8Q-0-10; PARTREV R07

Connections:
+3.3V: C16.1, C17.1, R27.1, R28.1, R29.1, R30.1, U3.2 (VCC_IO), U3.17 (VCC); also elsewhere on the board
EXTINT_SAM-M8Q: U3.19 (EXTINT0)
GND: C16.2, C17.2, U3.1 (GND), U3.4 (GND), U3.5 (GND), U3.6 (GND), U3.10 (GND), U3.11 (GND), U3.15 (GND), U3.16 (GND), U3.20 (GND); also elsewhere on the board
I2C_SCL: R29.2, U3.12 (SCL); also elsewhere on the board
I2C_SDA: R30.2, U3.9 (SDA); also elsewhere on the board
unnamed: R28.2, U3.3 (V_BCKP)
UART_RXD: R27.2, U3.14 (RXD)
UART_TXD: U3.13 (TXD)

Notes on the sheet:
ジャンパ抵抗
GNSS


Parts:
BZ1: UGCM1205XP; Buzzer_12x9.5RM7.6
C8, C9, C14, C15, C18: 0.1uF; C_0603_1608Metric_Pad1.08x0.95mm_HandSolder
J4: DF51-2P-2DS
Q3: 2SC3325-Y; SC-59_Handsoldering
R22: 4.7kR; R_0603_1608Metric_Pad0.98x0.95mm_HandSolder
R23, R24, R25: 10kR; R_0603_1608Metric_Pad0.98x0.95mm_HandSolder
U1, U2, U4: MB85RQ8MX; SOIC-16W_7.5x10.3mm_P1.27mm
U7: TC7S14F; TSOT-23-5_HandSoldering

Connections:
+3.3V: C9.2, C14.1, C15.1, C18.1, R24.2, U1.1 (~HOLD(IO3)), U1.2 (VDD), U1.9 (~WP(IO2)), U2.1 (~HOLD(IO3)), U2.2 (VDD), U2.9 (~WP(IO2)), U4.1 (~HOLD(IO3)), U4.2 (VDD), U4.9 (~WP(IO2)), U7.5 (VCC); also elsewhere on the board
+5V: BZ1.1 (-); also elsewhere on the board
BUZZER: R22.1; also elsewhere on the board
FLIGHT_PIN: U7.4; also elsewhere on the board
GND: C8.1, C9.1, C14.2, C15.2, C18.2, J4.1, Q3.2 (E), R23.1, U1.10 (VSS), U2.10 (VSS), U4.10 (VSS), U7.3 (GND); also elsewhere on the board
unnamed: BZ1.2 (+), Q3.3 (C)
unnamed: C8.2, R25.2, U7.2
unnamed: J4.2, R24.1, R25.1
unnamed: Q3.1 (B), R22.2, R23.2
SPI_MISO: U1.8 (SO(IO1)), U2.8 (SO(IO1)), U4.8 (SO(IO1)); also elsewhere on the board
SPI_MOSI: U1.15 (SI(IO0)), U2.15 (SI(IO0)), U4.15 (SI(IO0)); also elsewhere on the board
SPI_SCLK: U1.16 (SCK), U2.16 (SCK), U4.16 (SCK); also elsewhere on the board
SPI_~CS_FeRAM0: U1.7 (~CS); also elsewhere on the board
SPI_~CS_FeRAM1: U2.7 (~CS); also elsewhere on the board
SPI_~CS_FeRAM2: U4.7 (~CS); also elsewhere on the board

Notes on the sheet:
現在の状態を把握するため
FeRAM2
FeRAM0
FeRAM1
ブザー
フライトピン


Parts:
D8, D10: Green; LED_0603_1608Metric_Pad1.05x0.95mm_HandSolder
D9, D11: GS1010FL; D_SOD-123F
J5: DF51A-4P-2DSA
Q1, Q2: AO3400A; SOT-23
R15, R18: 300R; R_0603_1608Metric_Pad0.98x0.95mm_HandSolder
R16, R19: 10kR; R_0603_1608Metric_Pad0.98x0.95mm_HandSolder
R17, R20: 2.4kR; R_0603_1608Metric_Pad0.98x0.95mm_HandSolder

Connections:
+12V: D9.1 (K), D11.1 (K), J5.2, J5.4, R17.1, R20.1; also elsewhere on the board
GND: Q1.2 (S), Q2.2 (S), R16.1, R19.1; also elsewhere on the board
unnamed: D8.2 (A), R17.2
unnamed: D8.1 (K), D9.2 (A), J5.3, Q1.3 (D)
unnamed: D10.2 (A), R20.2
unnamed: D10.1 (K), D11.2 (A), J5.1, Q2.3 (D)
unnamed: Q1.1 (G), R15.2, R16.2
unnamed: Q2.1 (G), R18.2, R19.2
SN3: R15.1; also elsewhere on the board
SN4: R18.1; also elsewhere on the board

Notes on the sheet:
12V ラインをMOSFETにより駆動
SN4
SN3



Board: 2 copper layers, 90.0 x 70.0 mm, 74 parts (19 on the bottom side), 48 nets.

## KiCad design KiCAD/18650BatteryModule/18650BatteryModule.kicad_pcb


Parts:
BT1, BT2, BT3, BT4: 1042; BAT_1042; PARTREV E
D1: Green; LED_0603_1608Metric_Pad1.05x0.95mm_HandSolder
F1: Polyfuse; Fuse_Bourns_MF-RHT300
H1, H2, H3, H4: MountingHole; MountingHole_3.2mm_M3_Pad_TopBottom
J1: DF1B-2S-2.5R
J2: DF11-8DP-2DS
R1: 2.4kR; R_0603_1608Metric_Pad0.98x0.95mm_HandSolder
TP1: TestPoint; TestPoint_THTPad_D1.0mm_Drill0.5mm
TP2: TestPoint_GND; TestPoint_THTPad_1.0x1.0mm_Drill0.5mm

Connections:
/12V: J2.1, J2.2, R1.1
/BUS_GND: D1.1 (K), J2.3, J2.4
/CAN_H: J2.7, J2.8
/CAN_L: J2.5, J2.6
GND: BT4.N, J1.1, TP2.1
unnamed: BT1.N, BT2.P
unnamed: BT1.P, F1.2
unnamed: BT2.N, BT3.P
unnamed: BT3.N, BT4.P
unnamed: D1.2 (A), R1.2
unnamed: F1.1, J1.2, TP1.1

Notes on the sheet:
From Power Module
BUS



Board: 2 copper layers, 94.0 x 70.0 mm, 15 parts (2 on the bottom side), 11 nets.

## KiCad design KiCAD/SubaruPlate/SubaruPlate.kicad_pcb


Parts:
H1, H2, H3, H4: MountingHole; MountingHole_3.2mm_M3_Pad_TopBottom

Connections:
GND: H1.1, H2.1, H3.1, H4.1; also elsewhere on the board

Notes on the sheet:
M3 Mount


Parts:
C1, C14: 10uF; C_0603_1608Metric_Pad1.08x0.95mm_HandSolder
C2, C13: 0.1uF; C_0603_1608Metric_Pad1.08x0.95mm_HandSolder
J1: Wire_Soldering; PinHeader_1x04_P1.27mm_Vertical
R1, R2, R3, R14, R16: 10kR; R_0603_1608Metric_Pad0.98x0.95mm_HandSolder
U1, U6: LPS28DFW; CCLGA-7L

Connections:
+3.3V: C1.1, C2.1, C13.1, C14.1, J1.2, R2.1, R3.1, R14.1, R16.1, U1.6 (VDD), U6.2 (SA0), U6.6 (VDD)
GND: C1.2, C2.2, C13.2, C14.2, J1.1, R1.2, U1.5 (GND), U1.7 (LID), U6.5 (GND), U6.7 (LID); also elsewhere on the board
I2C_SCL: J1.4, R3.2, R16.2, U1.3 (SCL), U6.3 (SCL)
I2C_SDA: J1.3, R2.2, R14.2, U1.1 (SDA), U6.1 (SDA)
unnamed: R1.1, U1.2 (SA0)

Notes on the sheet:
I2C Address: 0x5D
I2C Address: 0x5C
データシート LPS28DFW
Adafruit LPS28
STマイクロ LPS28DFW
気圧センサー
I2C バス
参考資料

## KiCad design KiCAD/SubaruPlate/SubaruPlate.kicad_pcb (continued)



Board: 2 copper layers, 140.0 x 140.0 mm, 16 parts (2 on the bottom side), 5 nets.

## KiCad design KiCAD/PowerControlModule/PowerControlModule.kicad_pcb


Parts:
H1, H2, H3, H4: MountingHole; MountingHole_3.2mm_M3_Pad_TopBottom

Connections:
GND: H1.1, H2.1, H3.1, H4.1; also elsewhere on the board

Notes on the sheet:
マウント


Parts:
C13, C16, C17: 0.1uF; C_0603_1608Metric_Pad1.08x0.95mm_HandSolder
C14, C15: 15pF; C_0603_1608Metric_Pad1.08x0.95mm_HandSolder
C19, C20: 2.2uF; C_0603_1608Metric_Pad1.08x0.95mm_HandSolder
D3: Green; LED_0603_1608Metric_Pad1.05x0.95mm_HandSolder
D5: SMAJ45A; D_SMA
D10: SS2040FL; D_SOD-123F
J3: DF11-8DP-2DS
R21: 3.6kR; R_0603_1608Metric_Pad0.98x0.95mm_HandSolder
R24: 10kR; R_0603_1608Metric_Pad0.98x0.95mm_HandSolder
R25: 120R; R_0603_1608Metric_Pad0.98x0.95mm_HandSolder
U2: MCP2515-xST; TSSOP-20_4.4x6.5mm_P0.65mm
U8: MCP2562-E-SN; SOIC-8_3.9x4.9mm_P1.27mm
U9: MCP1792x-5002xCB; SOT-23_Handsoldering
Y1: 8MHz; Crystal_HC49-4H_Vertical

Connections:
+3.3V: C13.1, C16.2, R24.2, U2.20 (VDD), U8.5 (Vio); also elsewhere on the board
+5VD: C17.2, C20.1, D10.2 (A), U8.3 (VDD), U9.2 (VO)
+12V: C19.1, D5.1 (K), D10.1 (K), J3.1, J3.2, R21.1, U9.3 (VI); also elsewhere on the board
CAN_H: J3.7, J3.8, R25.2, U8.7 (CANH)
CAN_L: J3.5, J3.6, R25.1, U8.6 (CANL)
CAN_RX: U2.2 (RXCAN), U8.4 (RXD)
CAN_TX: U2.1 (TXCAN), U8.1 (TXD)
GND: C13.2, C14.2, C15.2, C16.1, C17.1, C19.2, C20.2, D3.1 (K), D5.2 (A), J3.3, J3.4, U2.10 (VSS), U8.2 (VSS), U8.8 (STBY), U9.1 (GND); also elsewhere on the board
unnamed: D3.2 (A), R21.2
unnamed: R24.1, U2.19 (~RESET)
OSC1: C14.1, U2.9 (OSC1), Y1.2
OSC2: C15.1, U2.8 (OSC2), Y1.1
SPI_CS_MCP2515: U2.18 (~CS); also elsewhere on the board
SPI_MISO: U2.17 (SO); also elsewhere on the board
SPI_MOSI: U2.16 (SI); also elsewhere on the board
SPI_SCK: U2.14 (SCK); also elsewhere on the board

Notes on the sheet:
終端抵抗．モジュールに応じて取り付ける．
CANトランシーバー
CAN バス
CANコントローラー


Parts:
C1: 220uF; CP_Radial_D6.3mm_P2.50mm
C2, C4: 22uF; C_0805_2012Metric_Pad1.18x1.45mm_HandSolder
C3, C5, C22: 0.1uF; C_0603_1608Metric_Pad1.08x0.95mm_HandSolder
C9: 2200uF; CP_Radial_D18.0mm_P7.50mm
C10: 0.1uF; C_0603_1608Metric
C11: 33uF; CP_Elec_6.3x5.9
C18, C21: 0.056uF; L_0603_1608Metric
D1, D2: Orange; LED_0603_1608Metric_Pad1.05x0.95mm_HandSolder
D4: SMAJ45A; D_SMA
D7, D8, D9: Red; LED_0603_1608Metric_Pad1.05x0.95mm_HandSolder
J1, J2: DF1B-2S-2.5R
Q1, Q2, Q4, Q5, Q7, Q9: AO3401A; SOT-23_Handsoldering
Q3: AO3400A; TSOT-23_HandSoldering
Q6, Q10: AO3401A; SOT-23; not fitted
Q11, Q12: Si4162DY; SOIC-8_3.9x4.9mm_P1.27mm
R3, R6, R7, R22, R26: 10kR; R_0603_1608Metric_Pad0.98x0.95mm_HandSolder
R4, R18, R19: 5.6kR; R_0603_1608Metric_Pad0.98x0.95mm_HandSolder
R5, R20: 3.3kR; R_0603_1608Metric_Pad0.98x0.95mm_HandSolder
R8: 4.7kR; R_0603_1608Metric_Pad0.98x0.95mm_HandSolder
R9, R13, R14: 680R; R_0603_1608Metric_Pad0.98x0.95mm_HandSolder
R10, R11, R12: 15mR; R_2512_6332Metric_Pad1.40x3.35mm_HandSolder
R15, R16: 2.7kR; R_0603_1608Metric_Pad0.98x0.95mm_HandSolder
R17: 820; R_0603_1608Metric_Pad0.98x0.95mm_HandSolder
R27: 10k; R_0603_1608Metric
TH1: Thermistor_NTC; PinHeader_1x02_P2.00mm_Vertical
U3, U4, U6: INA228; VSSOP-10_3x3mm_P0.5mm
U5: LTC4353; MSOP-16_3x4.039mm_P0.5mm
U11: LTC3119; StrawberryLinux_LTC3119

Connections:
+3.3V: C3.1, C5.1, C22.1, D7.2 (A), D8.2 (A), D9.2 (A), R26.1, R27.1, U3.6 (VS), U4.2 (A0), U4.6 (VS), U6.1 (A1), U6.2 (A0), U6.6 (VS); also elsewhere on the board
+12V: R12.2, U6.9 (Vin-); also elsewhere on the board
+VSW: Q7.2 (S), U11.12 (VIN), U11.13 (VIN), U11.14 (RUN)
/PowerControl/BATT: C2.1, J2.2, Q2.2 (S), R4.1
/PowerControl/BATT_LOWER: C21.2, Q12.1 (S), Q12.2 (S), Q12.3 (S), R11.1, U4.9 (Vin-), U5.4 (VIN2)
/PowerControl/BATT_UPPER: Q4.2 (S), R11.2, U4.8 (Vbus), U4.10 (Vin+)
/PowerControl/BUS_LOWER: C1.1, R12.1, U6.8 (Vbus), U6.10 (Vin+), U11.3 (VOUT), U11.4 (VOUT)
/PowerControl/GPU: C4.1, J1.2, Q5.2 (S), R7.1
/PowerControl/GPU_LOWER: C18.2, Q11.1 (S), Q11.2 (S), Q11.3 (S), R10.2, U3.9 (Vin-), U5.13 (VIN1)
/PowerControl/GPU_UPPER: Q9.2 (S), R10.1, U3.8 (Vbus), U3.10 (Vin+)
BATT_EN: R17.1; also elsewhere on the board
GND: C1.2, C3.2, C5.2, C9.2, C10.2, C22.2, J1.1, J2.1, Q3.2 (S), R3.2, R6.2, R8.2, R20.2, R22.2, TH1.2, U3.1 (A1), U3.2 (A0), U3.7 (GND), U4.1 (A1), U4.7 (GND), U5.15 (GND), U6.7 (GND), U11.1 (GND), U11.5 (GND), U11.6 (GND), U11.9 (GND), U11.10 (GND), U11.11 (GND), U11.16 (GND); also elsewhere on the board
I2C_SCL: U3.5 (SCL), U4.5 (SCL), U6.5 (SCL); also elsewhere on the board
I2C_SDA: U3.4 (SDA), U4.4 (SDA), U6.4 (SDA); also elsewhere on the board
LTC3119_PGOOD: R27.2, U11.2 (PGOOD); also elsewhere on the board
LTC4353_EN1: R3.1, U5.16 (EN1); also elsewhere on the board
LTC4353_EN2: R6.1, U5.1 (EN2); also elsewhere on the board
unnamed: D1.2 (A), R15.1
unnamed: D1.1 (K), U5.9 (ONST1)
unnamed: D2.2 (A), R16.1
unnamed: D2.1 (K), U5.8 (ONST1)
unnamed: C9.1, D4.2 (A), R18.1
unnamed: C11.1, D4.1 (K), Q1.2 (S), Q11.5 (D), Q11.6 (D), Q11.7 (D), Q11.8 (D), Q12.5 (D), Q12.6 (D), Q12.7 (D), Q12.8 (D), R15.2, R16.2, R18.2, R19.1, U5.7 (OUT2), U5.10 (OUT1)
unnamed: D7.1 (K), R9.1
unnamed: D8.1 (K), R13.1
unnamed: D9.1 (K), R14.1
unnamed: Q1.3 (D), Q7.3 (D)
unnamed: C11.2, Q1.1 (G), Q7.1 (G), R19.2, R20.1
unnamed: Q2.3 (D), Q4.3 (D)
unnamed: C2.2, Q2.1 (G), Q4.1 (G), R4.2, R5.1
unnamed: Q3.3 (D), R5.2
unnamed: Q3.1 (G), R17.2, R22.1
unnamed: Q5.3 (D), Q9.3 (D)
unnamed: C4.2, Q5.1 (G), Q9.1 (G), R7.2, R8.1
unnamed: Q11.4 (G), U5.12 (GATE1)
unnamed: Q12.4 (G), U5.5 (GATE2)
unnamed: R14.2, U3.3 (~Alert)
unnamed: R13.2, U4.3 (~Alert)
unnamed: C18.1, U5.11 (CPO1)
unnamed: C21.1, U5.6 (CPO2)
unnamed: C10.1, U5.14 (VCC)
unnamed: R9.2, U6.3 (~Alert)
unnamed: U11.7 (VCC), U11.8 (MPPC), U11.15 (PWM/SYNC)
VREF_T1: R26.2, TH1.1; also elsewhere on the board

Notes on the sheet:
SLAVE ADDRESS: 0b1000000
逆流防止ロードスイッチ
今までの接続 H-59 H-60
From Ground Power Unit [GPU] (External)
SLAVE ADDRESS: 0b100 0001
17V
15Vくらい
AO3401A
SLAVE ADDRESS: 100 0101
2:S
3:D
Pch MOSFET
From Battery Module (Internal)
1:G
R7, R8 で分圧して5.5Vくらい
0.015 ohm 1% 3W 電流検出抵抗
R4, R5 で分圧して5.5Vくらい
ソースとドレインのピン番号が反対で接続されていた


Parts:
D11: SS2040FL; D_SOD-123F
R1, R2, R23: 4.7kR; R_0603_1608Metric_Pad0.98x0.95mm_HandSolder
U1: XIAO-RP2040-DIP; XIAO-RP2040-SMD

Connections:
+3.3V: R1.1, R2.1, R23.1, U1.12 (3V3); also elsewhere on the board
+5V: D11.2 (A); also elsewhere on the board
BATT_EN: U1.7 (GPIO0/TX); also elsewhere on the board
GND: U1.13 (GND); also elsewhere on the board
I2C_SCL: R2.2, U1.6 (GPIO7/SCL); also elsewhere on the board
I2C_SDA: R1.2, U1.5 (GPIO6/SDA); also elsewhere on the board
LTC3119_PGOOD: U1.8 (GPIO1/RX); also elsewhere on the board
LTC4353_EN1: U1.3 (GPIO28/ADC2/A2); also elsewhere on the board
LTC4353_EN2: U1.4 (GPIO29/ADC3/A3); also elsewhere on the board
unnamed: D11.1 (K), U1.14 (VBUS)
SPI_CS_MCP2515: R23.2, U1.1 (GPIO26/ADC0/A0); also elsewhere on the board
SPI_MISO: U1.10 (GPIO4/MISO); also elsewhere on the board
SPI_MOSI: U1.11 (GPIO3/MOSI); also elsewhere on the board
SPI_SCK: U1.9 (GPIO2/SCK); also elsewhere on the board
VREF_T1: U1.2 (GPIO27/ADC1/A1); also elsewhere on the board


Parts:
D6: SS2040FL; D_SOD-123F
PS1: M78AR05-0.5; M78AR03305; Manufacturer_Part_Number M78AR05-0.5

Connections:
+5V: PS1.3 (+VOUT); also elsewhere on the board
+12V: D6.2 (A); also elsewhere on the board
GND: PS1.2 (GND); also elsewhere on the board
unnamed: D6.1 (K), PS1.1 (+VIN)

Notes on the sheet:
逆接続保護ダイオード
Switching Regulator
From BUS
To MCU


Board: 2 copper layers, 90.0 x 70.0 mm, 84 parts (1 on the bottom side), 60 nets.

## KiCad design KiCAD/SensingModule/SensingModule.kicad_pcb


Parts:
D1, D2: Blue; LED_0603_1608Metric_Pad1.05x0.95mm_HandSolder
H5, H6, H7, H8: MountingHole_Pad; MountingHole_3.2mm_M3_DIN965_Pad_TopBottom
J1: DF11-8DP-2DS
J2: MONITOR; DF11-8DP-2DS; not fitted
R1, R2: 680R; R_0603_1608Metric_Pad0.98x0.95mm_HandSolder
R5, R6, R7, R8, R9, R17: 4.7kR; R_0603_1608Metric_Pad0.98x0.95mm_HandSolder
U1: ARDUINO_MKR_WAN_1310; BOARD_ARDUINO_MKR_WAN_1310; PARTREV 06/27/2019

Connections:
+3.3V: J2.1, R5.2, R6.2, R7.2, R8.2, R17.2, U1.J5_12 (+3V3); also elsewhere on the board
+3.3VP: R9.2; also elsewhere on the board
+5V: U1.J5_13 (VIN); also elsewhere on the board
+12V: J1.1, J1.2; also elsewhere on the board
CAN_H: J1.7, J1.8; also elsewhere on the board
CAN_L: J1.5, J1.6; also elsewhere on the board
CAN_RECEIVE_STATUS: U1.J3_9 (PA22/D0(PWM)); also elsewhere on the board
CAN_SEND_STATUS: U1.J3_10 (PA23/D1(PWM)); also elsewhere on the board
GND: D1.1 (K), D2.1 (K), J1.3, J1.4, J2.2, U1.J5_11 (GND); also elsewhere on the board
I2C_SCL: J2.4, R8.1, U1.J5_7 (PA09/D12(PWM)/SCL(SC2)); also elsewhere on the board
I2C_SDA: J2.3, R7.1, U1.J5_6 (PA08/D11/SDA(SC2)); also elsewhere on the board
LORA_RECEIVE_STATUS: R1.1, U1.J3_13 (PB10/D4(PWM))
LORA_SEND_STATUS: R2.1, U1.J3_14 (PB11/D5(PWM))
unnamed: D1.2 (A), R1.2
unnamed: D2.2 (A), R2.2
SPI_CS_MCP: R9.1, U1.J5_2 (PA21/D7(PWM)); also elsewhere on the board
SPI_MISO: U1.J5_5 (PA19/D10(PWM)/CIPO(SC1)); also elsewhere on the board
SPI_MOSI: U1.J5_3 (PA16/D8(PWM)/COPI(SC1)); also elsewhere on the board
SPI_SCLK: U1.J5_4 (PA17/D9/SCK(SC1)); also elsewhere on the board
SPI_~CS_FeRAM0: R6.1, U1.J5_9 (PB22/D14/TX(SC5)); also elsewhere on the board
SPI_~CS_FeRAM1: R5.1, U1.J3_4 (PB03/D17/AIN(11)/A2); also elsewhere on the board
SPI_~CS_FeRAM2: R17.1, U1.J5_8 (PB23/D13/RX(SC5)); also elsewhere on the board
VREF_T1: J2.5, U1.J3_5 (PA04/D18(PWM)/AIN(4)/A3)
VREF_T2: J2.6, U1.J3_6 (PA05/D19(PWM)/AIN(5)/A4)
VREF_T3: J2.7, U1.J3_7 (PA06/D20/AIN(6)/A5)
VREF_T4: J2.8, U1.J3_8 (PA07/D21/AIN(7)/A6)
VREF_THERMISTOR: U1.J3_2 (PA02/D15/DAC0/AIN(0)/A0); also elsewhere on the board

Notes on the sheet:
LoRa Status
M3 MoutHole


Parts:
C4, C5, C6: 0.1uF; C_0603_1608Metric_Pad1.08x0.95mm_HandSolder
C7, C8: 15pF; C_0603_1608Metric_Pad1.08x0.95mm_HandSolder
D5, D6: Blue; LED_0603_1608Metric_Pad1.05x0.95mm_HandSolder
R11: 120R; R_0603_1608Metric_Pad0.98x0.95mm_HandSolder
R12, R13: 680R; R_0603_1608Metric_Pad0.98x0.95mm_HandSolder
R14: 10kR; R_0603_1608Metric_Pad0.98x0.95mm_HandSolder
U4: MCP2515-xST; TSSOP-20_4.4x6.5mm_P0.65mm
U9: MCP2562-E-SN; SOIC-8_3.9x4.9mm_P1.27mm
Y1: 8MHz; Crystal_HC49-4H_Vertical

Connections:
+3.3VP: C5.2, C6.2, R14.2, U4.20 (VDD), U9.5 (Vio); also elsewhere on the board
+5V: C4.2, U9.3 (VDD); also elsewhere on the board
CAN_H: R11.1, U9.7 (CANH); also elsewhere on the board
CAN_L: R11.2, U9.6 (CANL); also elsewhere on the board
CAN_RECEIVE_STATUS: R12.1; also elsewhere on the board
CAN_RX: U4.2 (RXCAN), U9.4 (RXD)
CAN_SEND_STATUS: R13.1; also elsewhere on the board
CAN_TX: U4.1 (TXCAN), U9.1 (TXD)
GND: C4.1, C5.1, C6.1, C7.2, C8.2, D5.1 (K), D6.1 (K), U4.10 (VSS), U9.2 (VSS), U9.8 (STBY); also elsewhere on the board
unnamed: D5.2 (A), R12.2
unnamed: D6.2 (A), R13.2
unnamed: R14.1, U4.19 (~RESET)
OSC1: C7.1, U4.9 (OSC1), Y1.2
OSC2: C8.1, U4.8 (OSC2), Y1.1
SPI_CS_MCP: U4.18 (~CS); also elsewhere on the board
SPI_MISO: U4.17 (SO); also elsewhere on the board
SPI_MOSI: U4.16 (SI); also elsewhere on the board
SPI_SCLK: U4.14 (SCK); also elsewhere on the board

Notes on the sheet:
CAN Status
CAN トランシーバー
CAN コントローラー

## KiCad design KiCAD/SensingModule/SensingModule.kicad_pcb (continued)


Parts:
C1: 330uF; CP_Elec_10x10
C10, C11: 1uF; C_0805_2012Metric_Pad1.18x1.45mm_HandSolder
D3: Green; LED_0603_1608Metric_Pad1.05x0.95mm_HandSolder
D7: SS2040FL; D_SOD-123F
PS1: M78AR05-0.5; M78AR03305; Manufacturer_Part_Number M78AR05-0.5
R10: 2.2kR; R_0603_1608Metric_Pad0.98x0.95mm_HandSolder
U8: RT9080-33GJ5; TSOT-23-5

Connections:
+3.3VP: C11.1, U8.5 (OUT); also elsewhere on the board
+5V: C10.1, PS1.3 (+VOUT), U8.1 (IN), U8.3 (EN); also elsewhere on the board
+12V: C1.1, D7.2 (A), R10.1; also elsewhere on the board
GND: C1.2, C10.2, C11.2, D3.1 (K), PS1.2 (GND), U8.2 (GND); also elsewhere on the board
unnamed: D3.2 (A), R10.2
unnamed: D7.1 (K), PS1.1 (+VIN)

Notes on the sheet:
本当は RT9080-33GJ5
逆接続保護ダイオード
12V Status
From BUS
To MCU
Switching Regulator
Linear Regulator
From DCDC


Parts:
C14, C15, C16: 0.1uF; C_0603_1608Metric_Pad1.08x0.95mm_HandSolder
J3: DF51-2P-2DS
J4: DF51A-4P-2DS
R15: 10kR; R_0603_1608Metric_Pad0.98x0.95mm_HandSolder
U2: BNO055; AE-BNO055-BO
U5, U6, U7: MB85RQ8MX; SOIC-16W_7.5x10.3mm_P1.27mm
U14: SOIC-16W_7.5x10.3mm_P1.27mm; not fitted

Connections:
+3.3V: C14.1, C15.1, C16.1, J4.2, R15.1, U2.1 (VIN), U5.1 (~HOLD(IO3)), U5.2 (VDD), U5.9 (~WP(IO2)), U6.1 (~HOLD(IO3)), U6.2 (VDD), U6.9 (~WP(IO2)), U7.1 (~HOLD(IO3)), U7.2 (VDD), U7.9 (~WP(IO2)), U14.8 (WP(IO2)), U14.9 (HOLD(IO3)), U14.10 (VDD); also elsewhere on the board
GND: C14.2, C15.2, C16.2, J3.1, J4.1, U2.2 (GND), U2.7 (GND), U5.10 (VSS), U6.10 (VSS), U7.10 (VSS), U14.7 (VSS); also elsewhere on the board
I2C_SCL: J4.4, U2.4 (SCL/R); also elsewhere on the board
I2C_SDA: J4.3, U2.3 (SDA/T); also elsewhere on the board
SPI_MISO: U5.8 (SO(IO1)), U6.8 (SO(IO1)), U7.8 (SO(IO1)), U14.16 (SO(IO1)); also elsewhere on the board
SPI_MOSI: U5.15 (SI(IO0)), U6.15 (SI(IO0)), U7.15 (SI(IO0)), U14.2 (SI(IO0)); also elsewhere on the board
SPI_SCLK: U5.16 (SCK), U6.16 (SCK), U7.16 (SCK), U14.1 (SCK); also elsewhere on the board
SPI_~CS_FeRAM0: U5.7 (~CS); also elsewhere on the board
SPI_~CS_FeRAM1: U6.7 (~CS); also elsewhere on the board
SPI_~CS_FeRAM2: U7.7 (~CS); also elsewhere on the board
VREF_THERMISTOR: J3.2, R15.2; also elsewhere on the board

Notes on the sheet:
THERMISTOR
LPS28DFW
FeRAM1
BNO055
FeRAM2
FeRAM0
Thermistor



Board: 2 copper layers, 90.0 x 70.0 mm, 48 parts (23 on the bottom side), 32 nets.

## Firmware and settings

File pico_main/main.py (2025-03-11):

from machine import Pin, PWM, UART
import utime

MID = 1500000
MIN = 1000000
MAX = 2000000

SERVO_MIN_ANGLE_X = -120
SERVO_MAX_ANGLE_X = 120
SERVO_MIN_ANGLE_Y = -45  # Adjusted limit for Y-axis servo
SERVO_MAX_ANGLE_Y = 90   # Adjusted limit for Y-axis servo

SERVO_MIN_PULSE_WIDTH = 1000000
SERVO_MAX_PULSE_WIDTH = 2000000

# Function to convert angle to pulse width
def angle_to_pulse_width(angle):
    return SERVO_MIN_PULSE_WIDTH + int((angle - SERVO_MIN_ANGLE_X) / (SERVO_MAX_ANGLE_X - SERVO_MIN_ANGLE_X) * (SERVO_MAX_PULSE_WIDTH - SERVO_MIN_PULSE_WIDTH))

# Setup servo pins
pin_x = 26
pin_y = 18
pwm_x = PWM(Pin(pin_x))
pwm_y = PWM(Pin(pin_y))

pwm_x.freq(50)
pwm_y.freq(50)
pwm_x.duty_ns(MID)
pwm_y.duty_ns(MID)

# Function to move servo to a specified angle
def move_to_angle(servo, angle):
    if servo == 'x':
        pwm = pwm_x
        min_angle = SERVO_MIN_ANGLE_X
        max_angle = SERVO_MAX_ANGLE_X
    elif servo == 'y':
        pwm = pwm_y
        min_angle = SERVO_MIN_ANGLE_Y
        max_angle = SERVO_MAX_ANGLE_Y
    else:
        print("Invalid servo selection")
        return
    
    angle = min(max(angle, min_angle), max_angle)  # Clamp angle within limits
    pulse_width = angle_to_pulse_width(angle)
    pwm.duty_ns(pulse_width)

# Move both motors to specified target angles
def move_to_target_angles(target_angle_x, target_angle_y):
    move_to_angle('x', target_angle_x)
    move_to_angle('y', target_angle_y)

# Function to handle UART input
def handle_uart_input():
    global received_data
    received_data = ""  # Initialize received_data if not defined
    while uart.any():
        received_data += uart.read().decode().strip()  # Accumulate received data
        if '\n' in received_data:  # Check if a complete command is received
            data, _, received_data = received_data.partition('\n')  # Split at newline
            print("Received:", data)  # Print received data
            if data == "u":
                return 0, 4  # Increase Y angle
            elif data == "d":
                return 0, -4  # Decrease Y angle
            elif data == "l":
                return -5, 0  # Decrease X angle
            elif data == "r":
                return 5, 0  # Increase X angle
            else:
                print("Invalid command:", data)
    return 0, 0  # Return default values if no valid command is received


# Configure UART communication
uart = UART(0, baudrate=115200)  # UART 0 is the default UART on Raspberry Pi Pico

target_angle_x = 0
target_angle_y = 0

# Main loop
if __name__ == "__main__":
    while True:
        delta_angle_x, delta_angle_y = handle_uart_input()
        target_angle_x = max(min(SERVO_MAX_ANGLE_X, target_angle_x + delta_angle_x), SERVO_MIN_ANGLE_X)
        target_angle_y = max(min(SERVO_MAX_ANGLE_Y, target_angle_y + delta_angle_y), SERVO_MIN_ANGLE_Y)
        move_to_target_angles(target_angle_x, target_angle_y)

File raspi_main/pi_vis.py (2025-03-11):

import serial
import cv2
import mediapipe as mp
from picamera2 import Picamera2
import threading
import time

uart = serial.Serial('/dev/ttyAMA0', baudrate=115200, timeout=0.001)  # Adjust port name if needed

# Initialize MediaPipe Face module
mp_face = mp.solutions.face_detection
face_detection = mp_face.FaceDetection()

# Initialize MediaPipe Face Landmarks module
mp_face_mesh = mp.solutions.face_mesh
face_mesh = mp_face_mesh.FaceMesh()

# Initialize PiCamera
picam2 = Picamera2()
picam2.sensor_resolution = (2304, 1296)  # Set the camera resolution
picam2.configure(picam2.create_preview_configuration(main={"format": 'XRGB8888', "size": (2304, 1296)}))
picam2.start()

# Set the desired processing resolution (keeping the original resolution)
processing_resolution = (picam2.sensor_resolution[0] // 4, picam2.sensor_resolution[1] // 4)

# Event for communication between threads
position_event = threading.Event()

# Function to process landmarks and print position
def process_landmarks(landmarks, bbox, iw, ih):
    for face_landmarks in landmarks.multi_face_landmarks:
        for lm in face_landmarks.landmark:
            # Extract landmark coordinates
            x, y = int(lm.x * iw), int(lm.y * ih)

            # Draw landmarks
            cv2.circle(resized_frame, (x, y), 1, (0, 0, 255), -1)

            # Set position event
            position_event.data = (x, y)
            position_event.set()

# Thread for printing position
def print_position():
    while True:
        if position_event.wait():  # Wait until position event is set
            position_event.clear()  # Clear the event for next iteration
            x, y = position_event.data
            
            # Check relative position
            # Add increment to check inside central 40/40 square instead of central point
            if x < processing_resolution[0] // 2 - 40: 
                uart.write("r\n".encode())
                print("right")
            elif x > processing_resolution[0] // 2 + 40:
                uart.write("l\n".encode())
                print("left")
        if position_event.wait():  # Wait until position event is set
            position_event.clear()  # Clear the event for next iteration
            x, y = position_event.data
            
            if y < processing_resolution[1] // 2 - 40:
                uart.write("u\n".encode())
                print("up")
            elif y > processing_resolution[1] // 2 + 40:
                uart.write("d\n".encode())
                print("down")

# Start the thread for printing position
position_thread = threading.Thread(target=print_position)
position_thread.daemon = True
position_thread.start()

while True:
    frame = picam2.capture_array()

    # Resize the frame by averaging 4x4 blocks of pixels
    resized_frame = cv2.resize(frame, processing_resolution, interpolation=cv2.INTER_AREA)

    # Convert the resized frame to RGB for MediaPipe
    rgb_frame = cv2.cvtColor(resized_frame, cv2.COLOR_BGR2RGB)

    # Detect faces
    face_results = face_detection.process(rgb_frame)

    # If faces are detected, process landmarks
    if face_results.detections:
        for detection in face_results.detections:
            # Extract bounding box
            bboxC = detection.location_data.relative_bounding_box
            ih, iw, _ = resized_frame.shape
            bbox = int(bboxC.xmin * iw), int(bboxC.ymin * ih), \
                   int(bboxC.width * iw), int(bboxC.height * ih)

            # Convert frame to RGB
            rgb_frame = cv2.cvtColor(resized_frame, cv2.COLOR_BGR2RGB)

            # Process face landmarks
            landmarks = face_mesh.process(rgb_frame)

            if landmarks.multi_face_landmarks:
                process_landmarks(landmarks, bbox, iw, ih)

    # Display the frame
    cv2.imshow("frame", resized_frame)

    # Wait for a key event (cv2.waitKey(1) allows the OpenCV window to update)
    key = cv2.waitKey(1) & 0xFF
    if key == ord("q"):
        break

# Release resources
cv2.destroyAllWindows()
picam2.stop()

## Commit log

2025-03-11 fixed center check point to larger square to reduce jitter
    [pi_vis.py]
2025-03-11 Increased Y axis speed to the limit of precision
